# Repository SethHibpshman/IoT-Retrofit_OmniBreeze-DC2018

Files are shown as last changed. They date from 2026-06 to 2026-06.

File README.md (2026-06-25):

# OmniBreeze-DC2018-ESPHome

> Retrofitting a dumb tower fan with ESP32, IR control, and LDR state feedback for full Home Assistant integration.

**By [SethHibpshman](https://github.com/SethHibpshman)**

---

## What Is This?

The OmniBreeze DC2018 is a 40" tower fan. Out of the box it has no smart home capability, only a physical remote and control panel. This project adds full Home Assistant integration with real-time state feedback, voice control, and a custom OLED display without modifying the fan's original electronics.

Unlike most IR integrations, this project reads the fan's actual state and reports it back to Home Assistant. Speed, breeze mode, and timer status are monitored in real time using light-dependent resistors (LDRs) positioned over the fan's indicator LEDs. Home Assistant always reflects the fan's current state, whether it was changed from Home Assistant, the physical control panel, or the original remote.

## Features

- **Full IR control:** power, speed, breeze mode, oscillation, and timer
- **Real-time state reading:** 11 LDRs monitor the fan's LEDs and report actual state back to Home Assistant
- **Home Assistant fan entity:** speed, oscillation, breeze mode, and timer exposed as native entities
- **Auto sleep-mode correction:** ESPHome detects unintended sleep-mode transitions and automatically restores the selected mode
- **Custom OLED display:** 128×32 SSD1306 display showing speed, breeze mode, and timer status, plus a logo when the fan is off
- **Custom 3D printed mount:** LDR frame and OLED enclosure designed in Autodesk Fusion and printed in PLA

---

## How It Works

### IR Control
The fan's IR protocol was discovered by brute-forcing NEC address and command combinations with a MicroPython script running on the ESP32. Once the five valid commands were identified, they were recreated in ESPHome using raw pulse timing that matched the working MicroPython implementation.

### State Feedback via LDRs
Every button on the fan cycles through multiple states, so command tracking alone cannot reliably determine the current operating mode. Eleven LDRs sit directly over the fan's indicator LEDs and are monitored by the ESP32's ADC. Threshold-based binary sensors convert the analog readings into clean on/off states for each indicator.

### 3D Printed Housing
A two-part enclosure was designed in Autodesk Fusion:
- **LDR frame:** positions all 11 LDRs directly over their corresponding LEDs
- **Top shell:** covers the frame and provides a mounting point for the SSD1306 OLED display
Both parts were printed in PLA on an Elegoo Neptune 3 Pro.

---

## Hardware

| Component | Details |
|---|---|
| Microcontroller | ESP32-S3 dev board |
| IR transmitter | 3-pin IR LED module (VCC, GND, DATA) |
| LDRs | GL5528 × 11 |
| Resistors | 10kΩ × 11 (voltage dividers) |
| Display | SSD1306 128×32 OLED (I2C) |
| Fan | OmniBreeze DC2018 40" Tower Fan |
| Power | USB (external) |

---

## Photos

<table>
<tr>
<td align="center">
<br>
LDR Frame Interior
</td>
<td align="center">
<br>
Front Panel Interior
</td>
</tr>

<tr>
<td align="center">
<br>
Fusion 360 Top Cover Design
</td>
<td align="center">
<br>
Printed Front Cover
</td>
</tr>

<tr>
<td align="center">
<br>
Fan Overview
</td>
<td align="center">
<br>
Internal Wiring
</td>
</tr>

<tr>
<td colspan="2" align="center">
Home Assistant Dashboard<br>
Home Assistant Dashboard
</td>
</tr>
</table>

---

## Repository Structure

```
OmniBreeze-DC2018-ESPHome/
├── firmware/
│   ├── esphome/omnibreeze-fan.yaml       # Full ESPHome config
│   └── micropython_ir_scraping/          # Micropython tools used to scrape IR commands
├── hardware/
│   ├── 3d_models/                 # 3D models of all printed parts
│   └── esp32-s3_n16r8/            # ESP module specific files
├── reference material/            # Datasheets for fan & linear power regulator on board
└── README.md
```

---

## What I Learned

**IR protocol reverse engineering is not always clean.** The ESPHome transmit_nec helper did not work with this fan because the generated timing differed from what the receiver expected. Switching to raw pulse arrays solved the issue. Matching the 9000µs header, 4500µs gap, and 560/1690µs bit timing produced reliable operation.

**Analog state detection is harder than it sounds.** Blue LEDs produced weaker responses from the LDRs than green or yellow LEDs. Two adjacent indicators, sleep breeze mode and the 1-hour timer LED, also created enough light leakage to generate nearly identical readings. A software rule resolves the ambiguity: when both sensors read high, the state is treated as a timer indicator rather than sleep mode.

**ESPHome's feedback loop problem is real.** Synchronizing the template fan entity with hardware sensor feedback without triggering command callbacks required several iterations. The final solution uses a one-second interval that updates the entity's internal state through publish_state().

**Power supply research matters.** The fan contains a KP3310DP offline AC-DC regulator capable of providing 5V output. Datasheet review suggested it could power the ESP32 internally, but testing showed the 138mA current limit could not handle Wi-Fi transmission spikes. Brownout resets occurred regularly, so the ESP32 was moved to a dedicated USB power supply.

---

## What I Would Do Differently

The ESP32 is currently powered through a USB cable routed outside the fan, requiring a second wall outlet. A small isolated AC-DC module such as the HLK-PM01 could be installed internally and power both the fan controller and ESP32 from a single plug. Testing showed the KP3310DP was not suitable for this role, but the HLK-PM01 would provide a straightforward solution.

---

## Wiki

Deep-dive documentation is in the [GitHub Wiki](../../wiki):

- [Hardware Overview & Wiring](../../wiki/Hardware-Overview)
- [IR Code Discovery](../../wiki/IR-Code-Discovery)
- [LDR Wiring & Calibration](../../wiki/LDR-Wiring-and-Calibration)
- [3D Model Design & Printing](../../wiki/3D-Models)
- [ESPHome Config Explained](../../wiki/ESPHome-Config)
- [Home Assistant Setup](../../wiki/Home-Assistant-Setup)
- [Troubleshooting](../../wiki/Troubleshooting)

---

## Built With

- [ESPHome](https://esphome.io/)
- [Home Assistant](https://www.home-assistant.io/)
- [Autodesk Fusion](https://www.autodesk.com/products/fusion-360/)
- [Elegoo Neptune 3 Pro](https://www.elegoo.com/)
- MicroPython (for IR discovery)

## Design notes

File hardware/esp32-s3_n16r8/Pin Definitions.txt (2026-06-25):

Pin definitions (Top to bottom):

(LEFT SIDE):
3V3
3V3
RST
4 (GPIO4, RTC, TOUCH4, ADC1_3)
5 (GPIO5, RTC, TOUCH5, ADC1_4)
6 (GPIO6, RTC, TOUCH6, ADC1_5)
7 (GPIO7, RTC, TOUCH7, ADC1_6)
15 (GPIO15, RTC, U0RTS, ADC2_4, XTAL_32K_P)
16 (GPIO16, RTC, U0CTS, ADC2_5, XTAL_32K_N)
17 (GPIO17, RTC, U1TXD, ADC2_6)
18 (GPIO18, RTC, U1RXD, ADC2_7, CLK_OUT3)
8 (GPIO8, RTC, TOUCH8, ADC1_7)
3 (GPIO3, RTC, TOUCH3, ADC1_2, JTAG)
46 (GPI46, LOG)
9 (GPIO9, RTC, TOUCH9, ADC1_8, SUBSPIHD, FSPIHD)
10 (GPIO10, TRC, TOUCH10, ADC1_9m FSPIIO4, SUBSPICS0, FSPICS0)
11 (GPIO11, RTC, TOUCH11, ADC2_0, FSPIIO5, SUBSPID, FSPID)
12 (GPIO12, RTC, TOUCH12, ADC2_1, FSPIIO6, SUBSPID, FSPICLK)
13 (GPIO13, RTC, TOUCH13, ADC2_2, FSPIIO7, SUBSPIQ, FSPIQ)
14 (GPIO14, RTC, TOUCH14, ADC2_3, FSPIDQS, SUBSPIWP, FSPIWP)
5V0
GND

(RIGHT SIDE):
GND
TX (U0TXD, GPIO43, CLK_OUT1)
RX (U0RXD, GPIO44, CLK_OUT2)
1 (GPIO1, RTC, TOUCH1, ADC1_0)
2 (GPIO2, RTC, TOUCH2, ADC1_1)
42 (MTMS, GPIO42)
41 (MTDI, GPIO41, CLK_OUT1)
40 (MTDO, GPIO40, CLK_OUT2)
39 (MTCK, GPIO39, CLK_OUT3, SUBSPICS1)
38 (GPIO38, FSPIWP, SUBSPIWP)
37 (GPIO37, SPIDQS, FSPIQ, SUBSPIQ)
36 (GPIO36, SPIIO7 FSPICLK, SUBSPICLK)
35 (GPIO35, SPIIO6, FSPID, SUBSPID)
0 (GPIO0, BOOT)
45 (GPIO45, VSPI)
48 (GPIO48, SPICLK_N)
47 (GPIO47, SPICLK_P, RGB_LED)
21 (GPIO21, RTC)
20 (USB_D+, GPIO20, RTC, U1CTS, ADC2_9, CLK_OUT1)
19 (USB_D-, GPIO19, RTC, U1RTS, ADC2_8, CLK_OUT2)
GND
GND

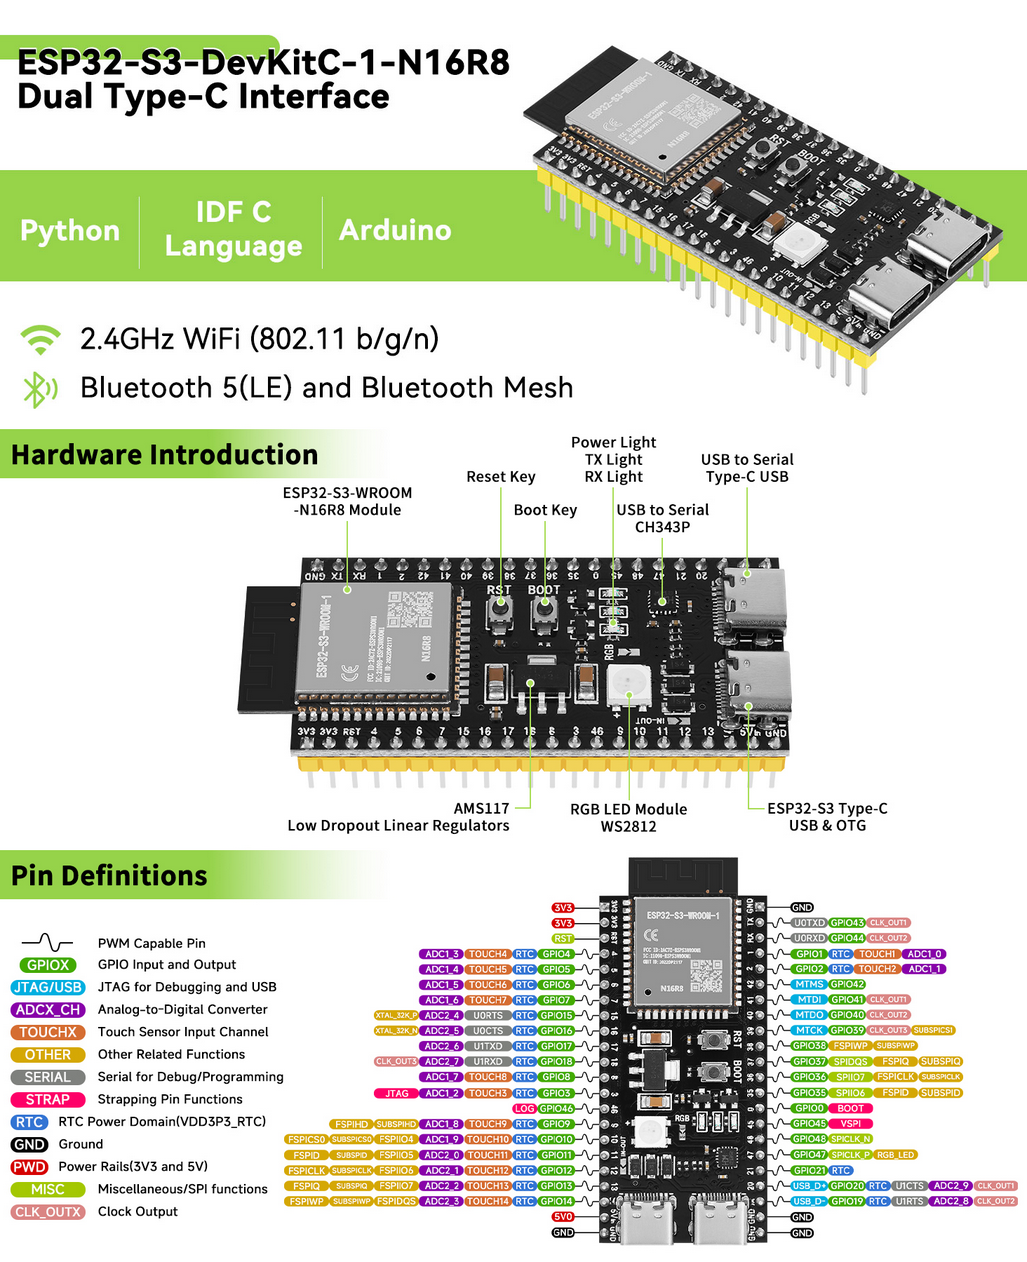
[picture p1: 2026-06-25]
hardware/esp32-s3_n16r8/ESP32-S3-DevKitC-1-N16R8 - Spec Infographic.png

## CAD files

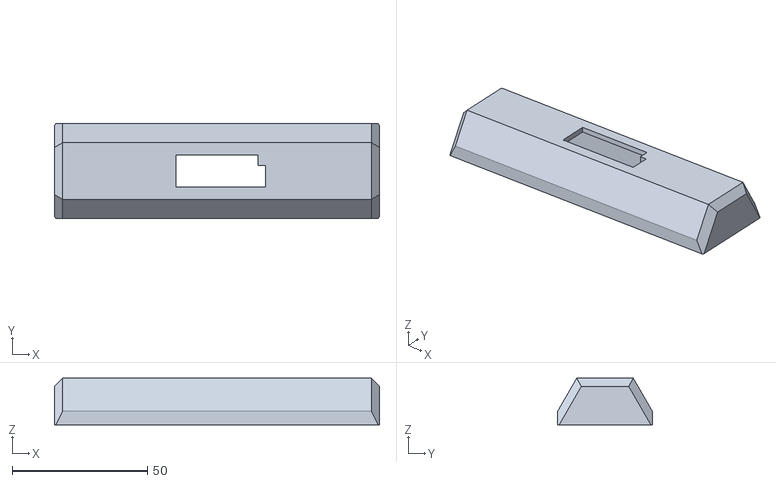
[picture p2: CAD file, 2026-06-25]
hardware/3d_models/Smart Fan Shroud Top.stl
120.0 x 35.0 x 17.2

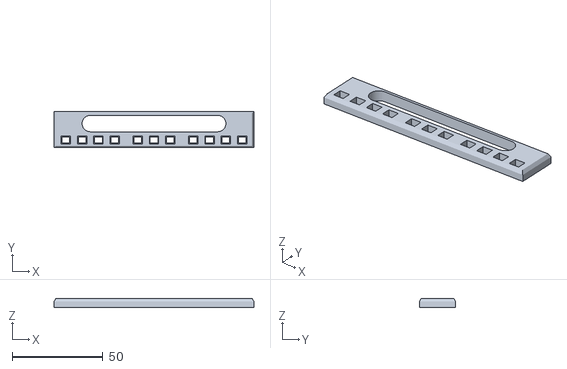
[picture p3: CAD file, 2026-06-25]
hardware/3d_models/Smart Fan Shroud.stl
110.0 x 20.0 x 5.00

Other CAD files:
hardware/3d_models/Smart Fan Shroud Top.f3d
hardware/3d_models/Smart Fan Shroud.f3d

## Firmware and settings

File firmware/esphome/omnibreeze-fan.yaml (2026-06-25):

esphome:
  name: omnibreeze-fan
  friendly_name: OmniBreeze Fan

esp32:
  board: esp32-s3-devkitc-1
  framework:
    type: arduino

logger:

api:
  encryption:
    key: XXXXXXXXXXXXXX

ota:
  - platform: esphome

wifi:
  ssid: !secret wifi_ssid
  password: !secret wifi_password
  ap:
    ssid: omnibreeze-fan Fallback Hotspot
    password: XXXXXXXXXXXXXX

remote_transmitter:
  pin: GPIO4
  carrier_duty_percent: 50%

i2c:
  sda: GPIO21
  scl: GPIO18

globals:
  - id: oscillation_state
    type: bool
    restore_value: no
    initial_value: 'false'

font:
  - file: "gfonts://Roboto Mono"
    id: font_main
    size: 9

image:
  - file: "sh_logo.png"
    id: fan_logo
    type: BINARY
    invert_alpha: true

interval:
  - interval: 1s
    then:
      - lambda: |-
          // Sync breeze select
          std::string breeze = "standard";
          if (id(led_breeze2).state) breeze = "natural";
          id(breeze_mode).publish_state(breeze);

          // Sync timer select
          int hours = (id(led_timer1).state ? 1 : 0)
                    + (id(led_timer2).state ? 2 : 0)
                    + (id(led_timer3).state ? 4 : 0)
                    + (id(led_timer4).state ? 8 : 0);
          std::string timer = "off";
          if (hours == 1)  timer = "1h";
          if (hours == 2)  timer = "2h";
          if (hours == 3)  timer = "3h";
          if (hours == 4)  timer = "4h";
          if (hours == 5)  timer = "5h";
          if (hours == 6)  timer = "6h";
          if (hours == 7)  timer = "7h";
          if (hours == 8)  timer = "8h";
          if (hours == 9)  timer = "9h";
          if (hours == 10) timer = "10h";
          if (hours == 11) timer = "11h";
          if (hours == 12) timer = "12h";
          if (hours == 13) timer = "13h";
          if (hours == 14) timer = "14h";
          if (hours == 15) timer = "15h";
          id(fan_timer_select).publish_state(timer);
    
sensor:
  - platform: adc
    pin: GPIO1
    id: ldr_speed1
    name: "LDR Speed 1 Raw"
    update_interval: 100ms
    attenuation: 12db
    filters:
      - sliding_window_moving_average:
          window_size: 5
          send_every: 1

  - platform: adc
    pin: GPIO2
    id: ldr_speed2
    name: "LDR Speed 2 Raw"
    update_interval: 100ms
    attenuation: 12db
    filters:
      - sliding_window_moving_average:
          window_size: 5
          send_every: 1

  - platform: adc
    pin: GPIO3
    id: ldr_speed3
    name: "LDR Speed 3 Raw"
    update_interval: 100ms
    attenuation: 12db
    filters:
      - sliding_window_moving_average:
          window_size: 5
          send_every: 1

  - platform: adc
    pin: GPIO8
    id: ldr_speed4
    name: "LDR Speed 4 Raw"
    update_interval: 100ms
    attenuation: 12db
    filters:
      - sliding_window_moving_average:
          window_size: 5
          send_every: 1

  - platform: adc
    pin: GPIO9
    id: ldr_breeze1
    name: "LDR Breeze 1 Raw"
    update_interval: 100ms
    attenuation: 12db
    filters:
      - sliding_window_moving_average:
          window_size: 5
          send_every: 1

  - platform: adc
    pin: GPIO10
    id: ldr_breeze2
    name: "LDR Breeze 2 Raw"
    update_interval: 100ms
    attenuation: 12db
    filters:
      - sliding_window_moving_average:
          window_size: 5
          send_every: 1

  - platform: adc
    pin: GPIO11
    id: ldr_breeze3
    name: "LDR Breeze 3 Raw"
    update_interval: 100ms
    attenuation: 12db
    filters:
      - sliding_window_moving_average:
          window_size: 5
          send_every: 1

  - platform: adc
    pin: GPIO12
    id: ldr_timer1
    name: "LDR Timer 1 Raw"
    update_interval: 100ms
    attenuation: 12db
    filters:
      - sliding_window_moving_average:
          window_size: 5
          send_every: 1

  - platform: adc
    pin: GPIO13
    id: ldr_timer2
    name: "LDR Timer 2 Raw"
    update_interval: 100ms
    attenuation: 12db
    filters:
      - sliding_window_moving_average:
          window_size: 5
          send_every: 1

  - platform: adc
    pin: GPIO14
    id: ldr_timer3
    name: "LDR Timer 3 Raw"
    update_interval: 100ms
    attenuation: 12db
    filters:
      - sliding_window_moving_average:
          window_size: 5
          send_every: 1

  - platform: adc
    pin: GPIO17
    id: ldr_timer4
    name: "LDR Timer 4 Raw"
    update_interval: 100ms
    attenuation: 12db
    filters:
      - sliding_window_moving_average:
          window_size: 5
          send_every: 1
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
